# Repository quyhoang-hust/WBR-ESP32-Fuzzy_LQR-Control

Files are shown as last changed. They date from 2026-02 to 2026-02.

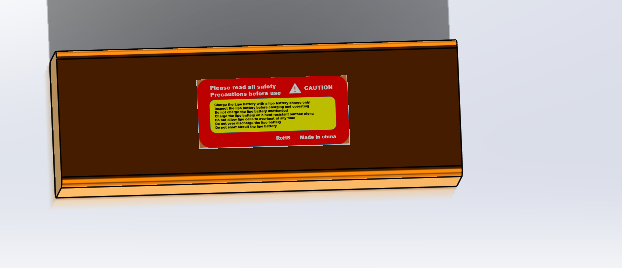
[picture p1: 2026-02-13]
Hardware/lipo-battery-12v-1.snapshot.17/2.PNG

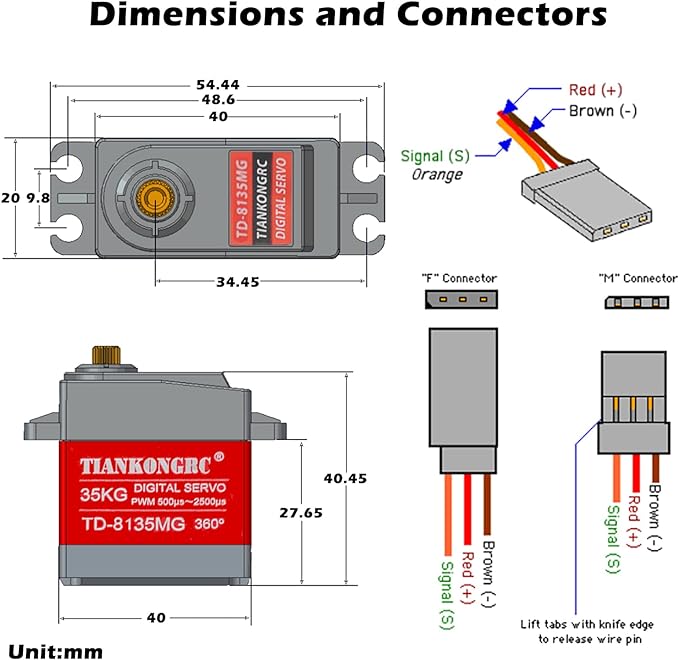
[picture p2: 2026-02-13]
Hardware/servo/TD-8135MG.jpg

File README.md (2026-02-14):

# 🤖 WBR with Fuzzy-LQR Controller
### Wheeled-Bipedal Technology | Advanced Control Systems

Dự án nghiên cứu và triển khai hệ thống điều khiển phản hồi trạng thái (LQR) kết hợp logic mờ (Fuzzy) cho robot lưỡng thăng có bánh (WBR) trên nền tảng ESP32.

## 🧠 Kiến trúc điều khiển (Control Architecture)
Dự án thực hiện bài toán cân bằng động cho robot bằng cách kết hợp giữa lý thuyết điều khiển hiện đại và logic mờ:

* **LQR (Linear Quadratic Regulator):** Sử dụng bộ điều khiển phản hồi trạng thái $u = -Kx$ để giữ thăng bằng. Hệ thống dựa trên vector trạng thái bao gồm: $[ \theta, \dot{\theta}, x, \dot{x} ]^T$.
* **Fuzzy Logic (Gain Scheduling):** Đóng vai trò là bộ điều chỉnh thông số thông minh. Dựa vào góc khớp chân thực tế (`servoAngle`), hệ thống thực hiện nội suy các thông số $K$ và $Target Angle$ phù hợp thông qua hàm membership tam giác (Low, Mid, High).
* **Complementary Filter (Bộ lọc bù):** Xử lý tín hiệu từ MPU6050 với hệ số $\alpha = 0.98$ để triệt tiêu nhiễu của gia tốc kế và hiện tượng trôi (drift) của con quay hồi chuyển, đảm bảo dữ liệu góc nghiêng $\theta$ luôn ổn định.

## 🏗 Kiến trúc phần mềm (Software Architecture)
Mã nguồn được thiết kế theo hướng **Modular Programming**, tận dụng tối đa khả năng xử lý song song trên **Dual-core** của ESP32 thông qua **FreeRTOS**:

### **Core 1: High Priority (Nhiệm vụ điều khiển)**
* **TaskSensor (100Hz):** Đọc cảm biến I2C, tính toán bộ lọc bù và giải mã Encoder.
* **TaskController (100Hz):** Thực thi thuật toán Fuzzy + LQR. Tính toán tín hiệu điện áp $u$ và đẩy vào hàng đợi (`Queue`).
* **TaskMotor:** Chấp hành tín hiệu PWM điều khiển driver BTS7960 với tần số 5kHz.

### **Core 0: Low Priority (Nhiệm vụ phụ trợ)**
* **TaskPosture (20Hz):** Quản lý khớp chân qua RC Servos với tính năng **Smooth Transition** (thay đổi 1° mỗi chu kỳ) để bảo vệ cơ cấu cơ khí.
* **TaskDebug:** Giao tiếp Serial, nhận lệnh thay đổi chiều cao thời gian thực và xuất dữ liệu ra Serial Plotter.

## 📺 Video vận hành thực tế
<div align="center">
  <a href="https://www.youtube.com/watch?v=h3YY7-l_Uk0">
    WBR Robot Balancing
  </a>
  <br>
  <b>Nhấn vào hình ảnh trên để xem video demo trên YouTube</b>
</div>

## 📂 Tổ chức mã nguồn
* `Firmware/`: Chứa mã nguồn chính chia theo các khối chức năng (`SensorBlock`, `ControlBlock`, `MotorBlock`,...).
* `Hardware/`: Thiết kế cơ khí, Mô hình 3D.
* `Documentation/`: Sơ đồ nguyên lý, Sơ đồ đi dây, Hình ảnh robot vận hành và kết quả mô phỏng/debug.

## 🚀 Hướng dẫn vận hành
1. Nạp code vào ESP32 thông qua Arduino IDE hoặc PlatformIO.
2. Mở **Serial Monitor/Plotter** ở baudrate `115200`.
3. Để thay đổi độ cao robot: Nhập giá trị góc từ `115` đến `155` vào Serial. Hệ thống Fuzzy sẽ tự động điều chỉnh bộ tham số $K$ tương ứng.

---
**Author:** Hoang Xuan Quy
**Project Status:** Đã cập nhật đầy đủ chức năng Fuzzy + LQR và RTOS.

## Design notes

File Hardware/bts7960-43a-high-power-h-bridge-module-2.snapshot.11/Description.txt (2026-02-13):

BTS7960 43A High Power H Bridge Module

https://grabcad.com/library/bts7960-43a-high-power-h-bridge-module-1

Buy Link:
https://www.aliexpress.us/item/3256805818916954.html

#CAD #SolidWorks #3dmodel #BTS7960 #43A #HBridge #DCMotors

The nice thing I like about this driver is I am able to control motor direction with 4 pins on the Arduino:
L_EN, R_EN, LPWM, RPWM

BTS7960B H-bridge 43A high-power motor driver Module Overview:

This driver uses Infineon chips BTS7960 composed of high-power drive full H-bridge driver module with thermal over-current protection.

Double BTS7960 H-bridge driver circuit, with a strong drive and braking, effectively isolating the microcontroller and motor driver!

Features:

Double BTS7960 large current (43 A) H bridge driver;

5V isolate with MCU, and effectively protects MCU;

5V power indicator on board;

Voltage indication of motor driver output end;

Can solder heat sink;

Just need four lines from MCU to driver module
(GND. 5V. PWM1. PWM2);

Isolation chip 5 V power supply
(can share with MCU 5 V);

SIZE: 4 * 5 * 1.2 cm;

Two PWM input frequency up to 25kHZ;

Supply voltage 5.5V to 27V;

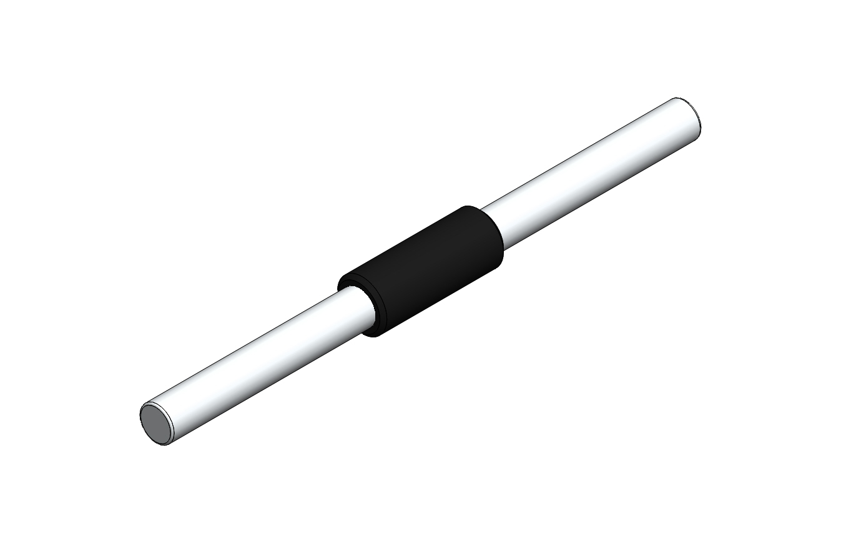
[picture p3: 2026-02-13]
Hardware/mpu-6050-sensor-1.snapshot.1/Gyroscopic sensor/Gyroscope sensor straight lead.JPG

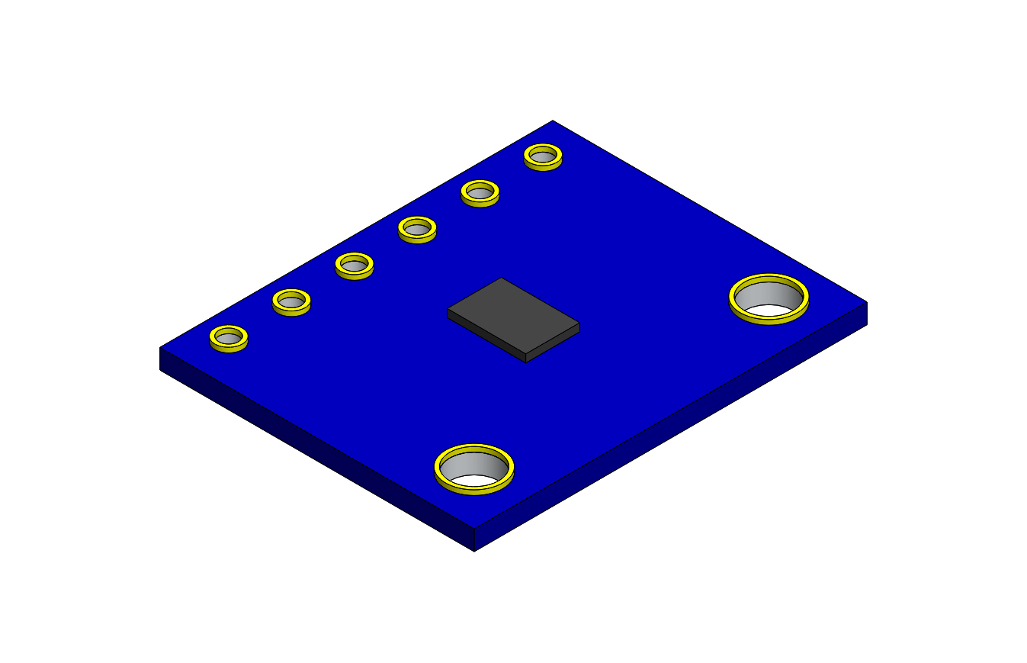
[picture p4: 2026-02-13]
Hardware/mpu-6050-sensor-1.snapshot.1/Gyroscopic sensor/Gyroscope sensor.JPG

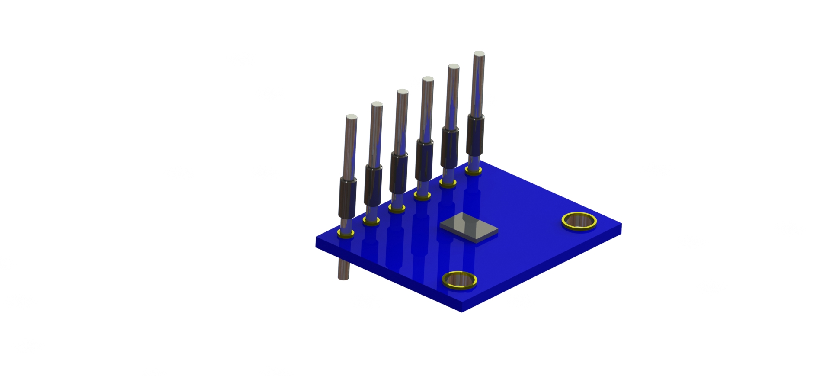
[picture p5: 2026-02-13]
Hardware/mpu-6050-sensor-1.snapshot.1/Gyroscopic sensor/MPU 6050 RENDER.JPG

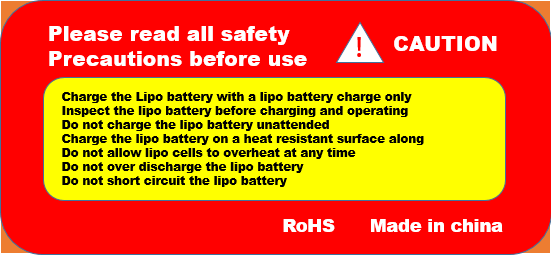
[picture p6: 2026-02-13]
Hardware/lipo-battery-12v-1.snapshot.17/pin2.PNG

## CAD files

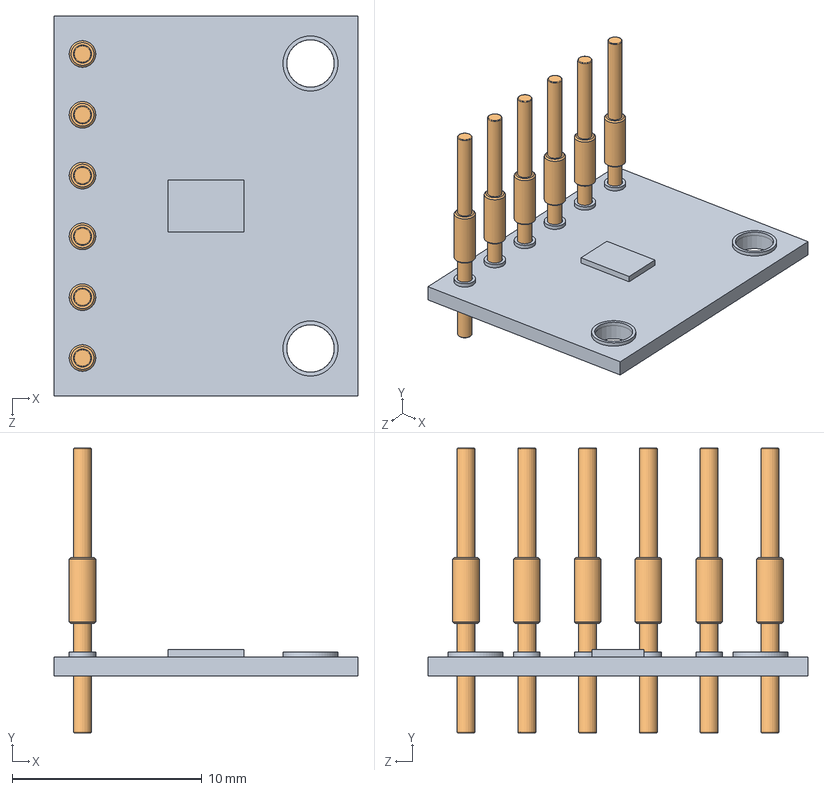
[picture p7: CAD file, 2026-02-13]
Hardware/mpu-6050-sensor-1.snapshot.1/Gyroscopic sensor/Gyrosensor.SLDASM
16.0 x 15.0 x 20.0 mm
Gyroscope sensor
Gyroscope sensor straight lead x 6

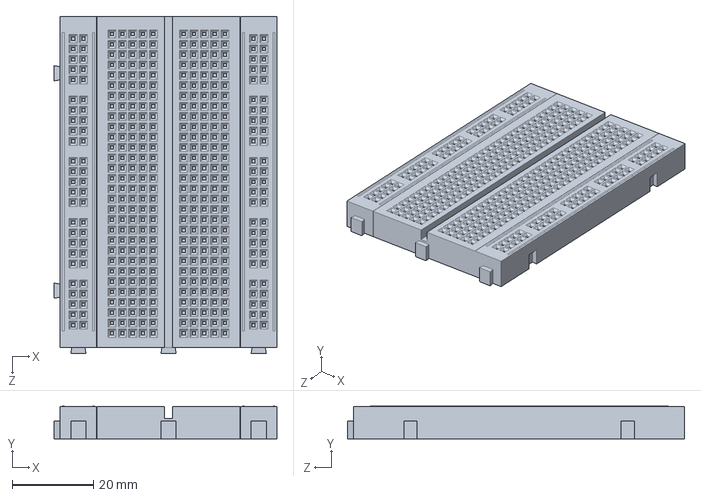
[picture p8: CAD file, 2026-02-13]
Hardware/breadboard-13.snapshot.4/Breadboard_400pin.SLDPRT
54.9 x 8.01 x 83.0 mm

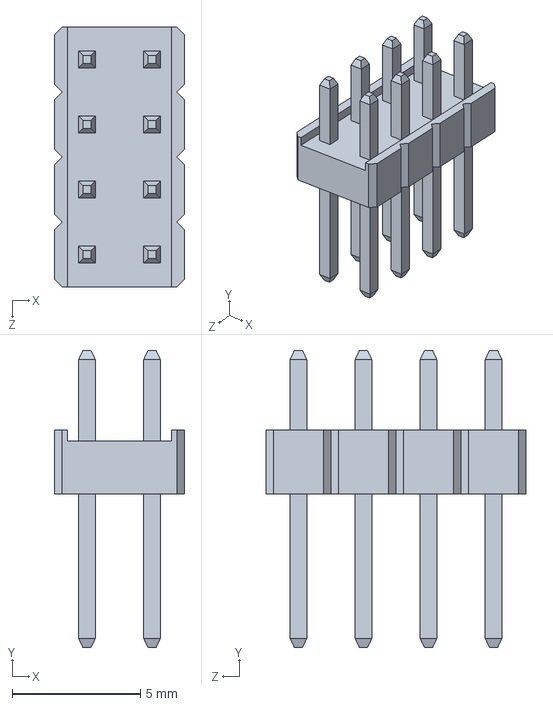
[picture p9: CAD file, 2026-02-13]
Hardware/bts7960-43a-high-power-h-bridge-module-2.snapshot.11/8 PIN HEADER, IC, BTS7960 43A HIGH POWER H BRIDGE MODULE.SLDPRT
5.08 x 11.6 x 10.2 mm

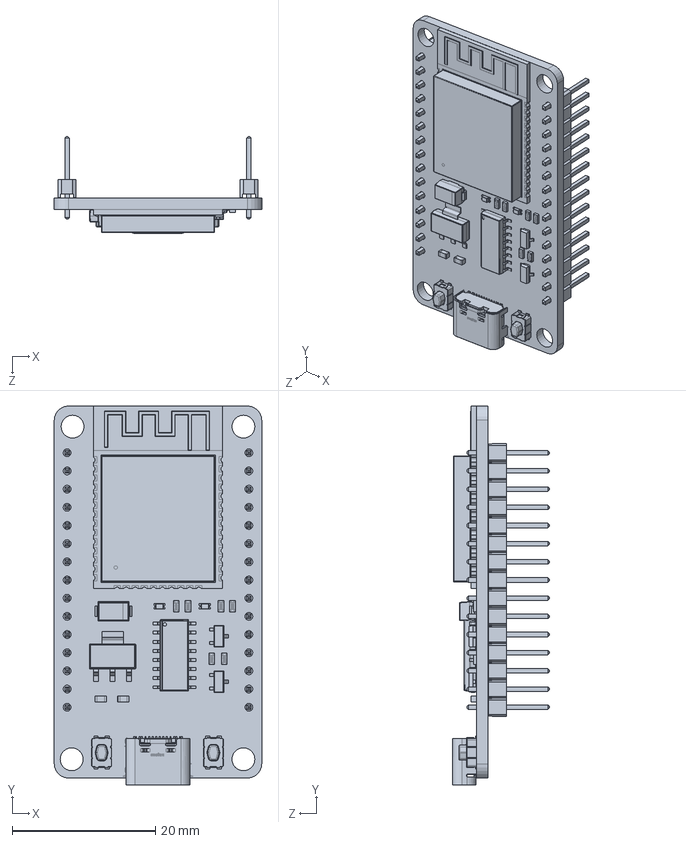
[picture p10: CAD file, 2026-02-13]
Hardware/development-board-esp32-ch340-1.snapshot.2/esp32_30pin_CH340.SLDPRT
29.0 x 53.0 x 13.5 mm

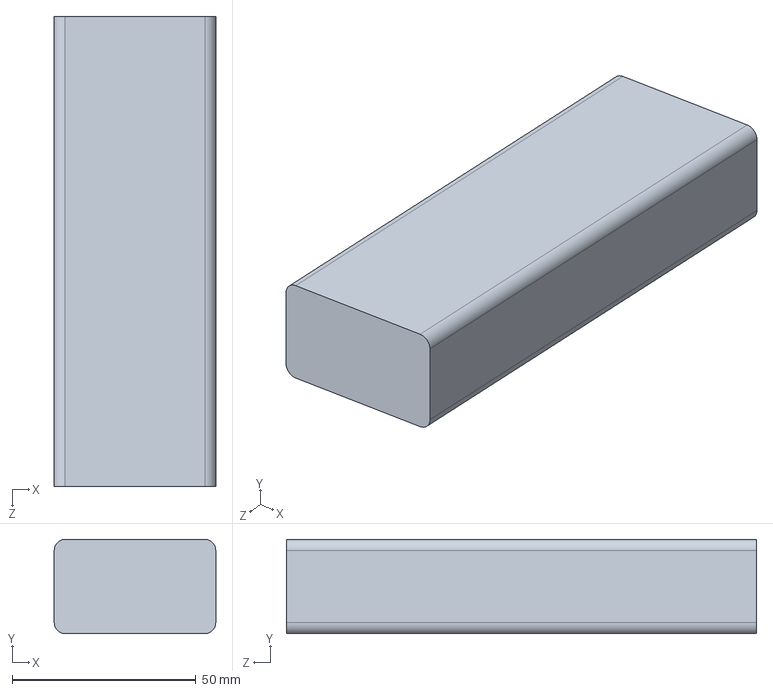
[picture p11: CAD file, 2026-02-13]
Hardware/lipo-battery-12v-1.snapshot.17/Lipo_Battery_12v_step.STEP
44.0 x 25.7 x 128.0 mm

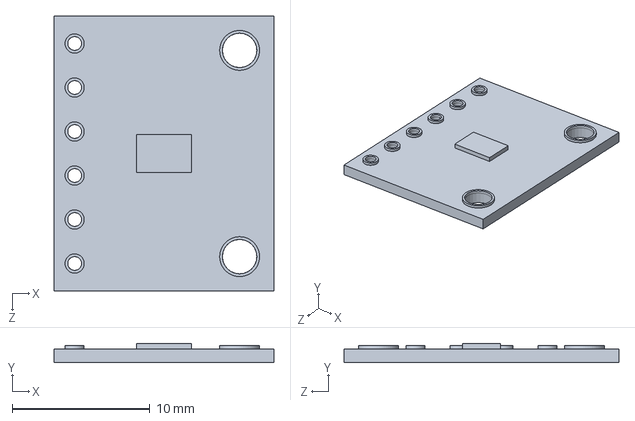
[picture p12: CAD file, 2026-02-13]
Hardware/mpu-6050-sensor-1.snapshot.1/Gyroscopic sensor/Gyroscope sensor.SLDPRT
16.0 x 1.40 x 20.0 mm

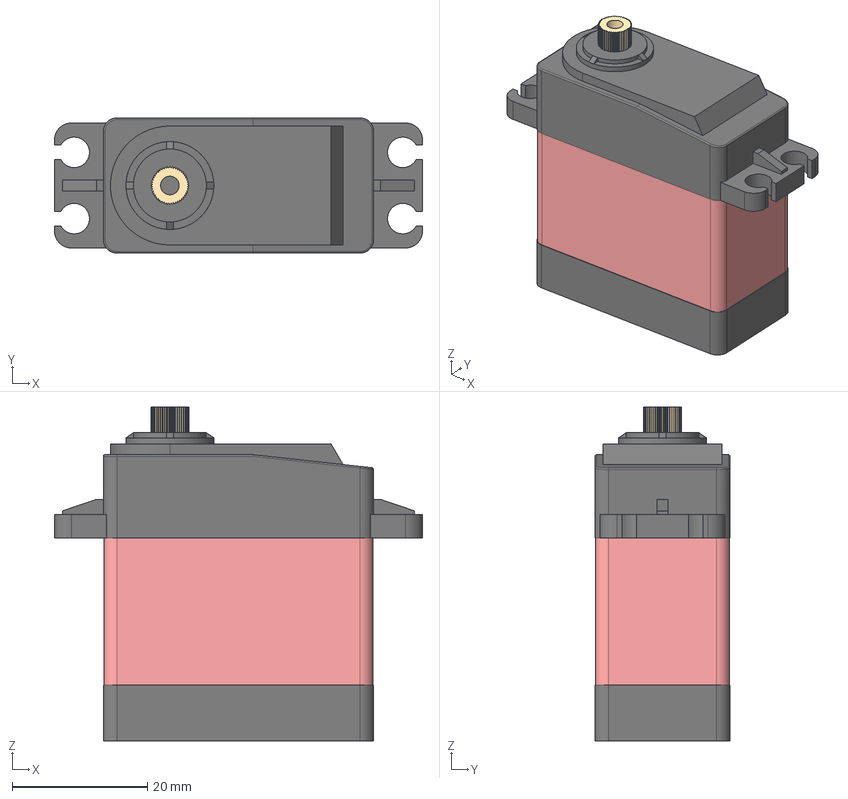
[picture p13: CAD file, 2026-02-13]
Hardware/servo/TD-8135MG Servo v5.step
54.4 x 20.0 x 49.4 mm

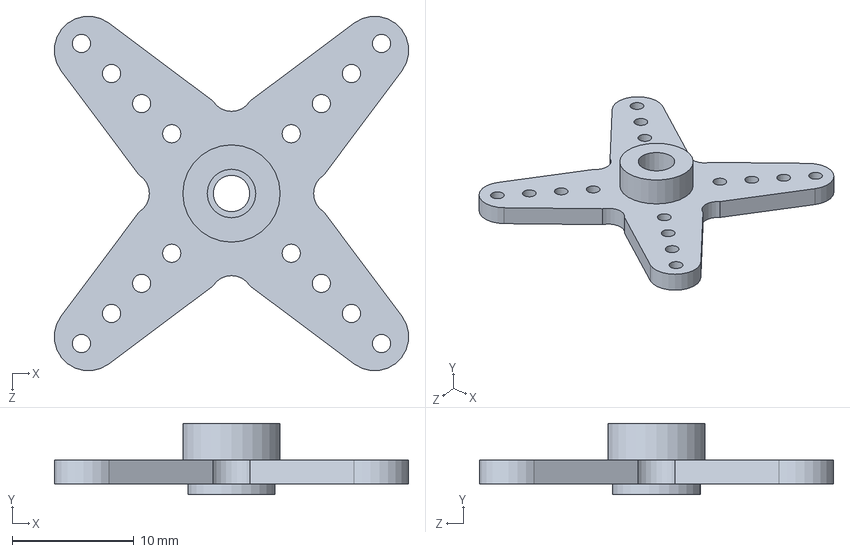
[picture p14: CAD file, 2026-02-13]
Hardware/servo_horn/futaba_horn_type_A.SLDPRT
29.1 x 5.85 x 29.1 mm

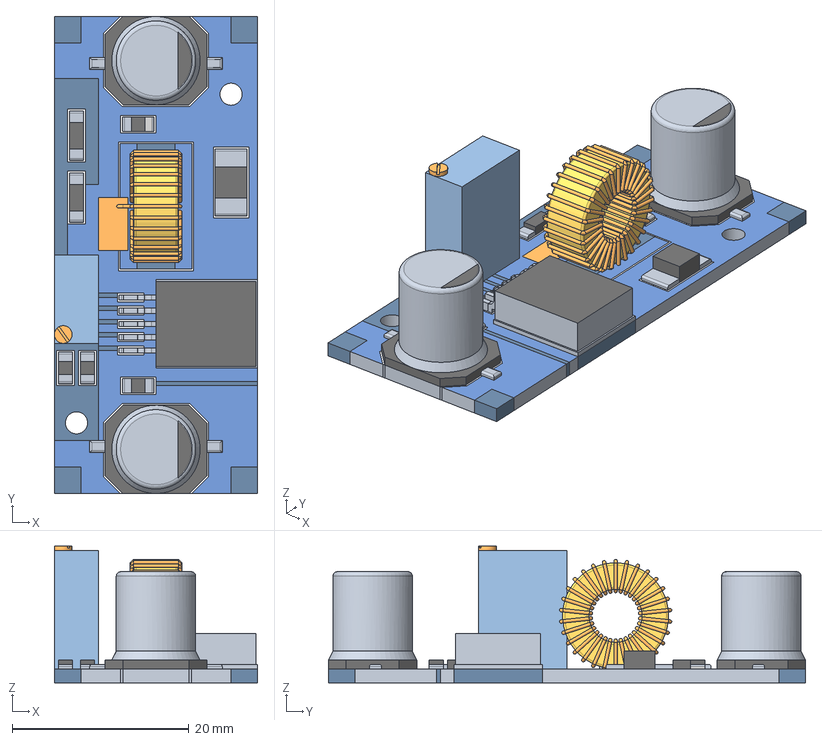
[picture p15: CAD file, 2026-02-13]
Hardware/step-down-xl4015-1.snapshot.2/Step Down XL4015.step
23.0 x 54.0 x 15.5 mm

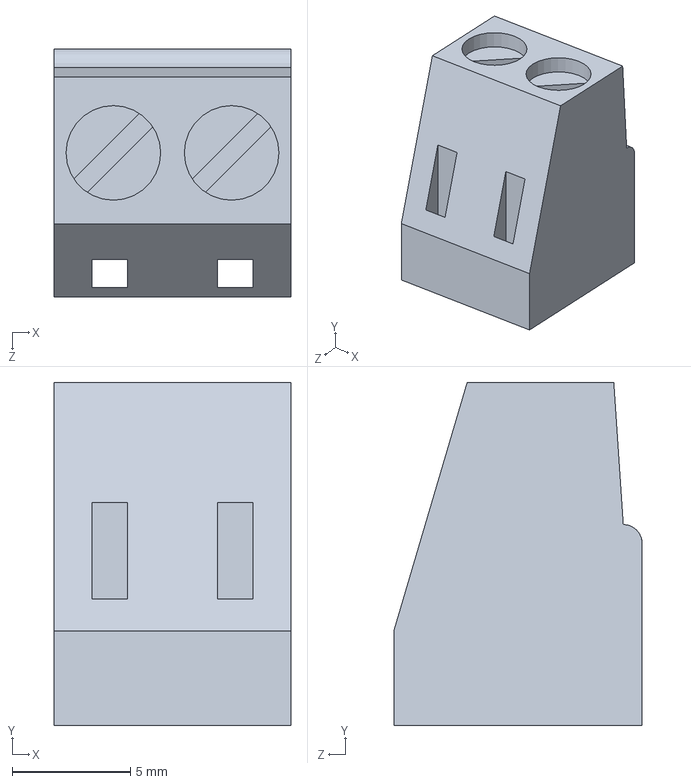
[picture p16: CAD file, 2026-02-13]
Hardware/bts7960-43a-high-power-h-bridge-module-2.snapshot.11/EUROSTYLE TERMINAL BLOCK 2 POS 5.0 MM RA PLUG, BTS7960 43A HIGH POWER H BRIDGE MODULE.SLDPRT
10.0 x 14.5 x 10.5 mm

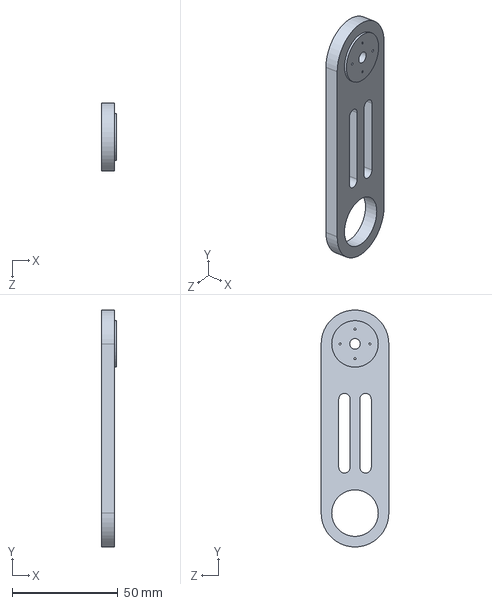
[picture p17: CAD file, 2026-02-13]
Hardware/Leg_Up_Front.SLDPRT
7.00 x 112.0 x 32.0 mm

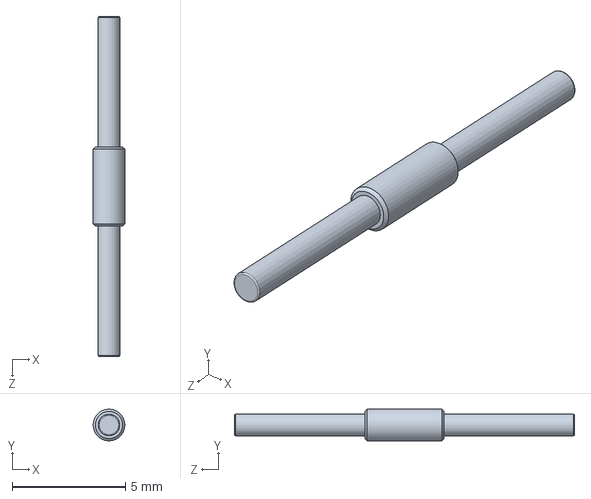
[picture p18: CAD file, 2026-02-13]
Hardware/mpu-6050-sensor-1.snapshot.1/Gyroscopic sensor/Gyroscope sensor straight lead.SLDPRT
1.40 x 1.40 x 15.0 mm

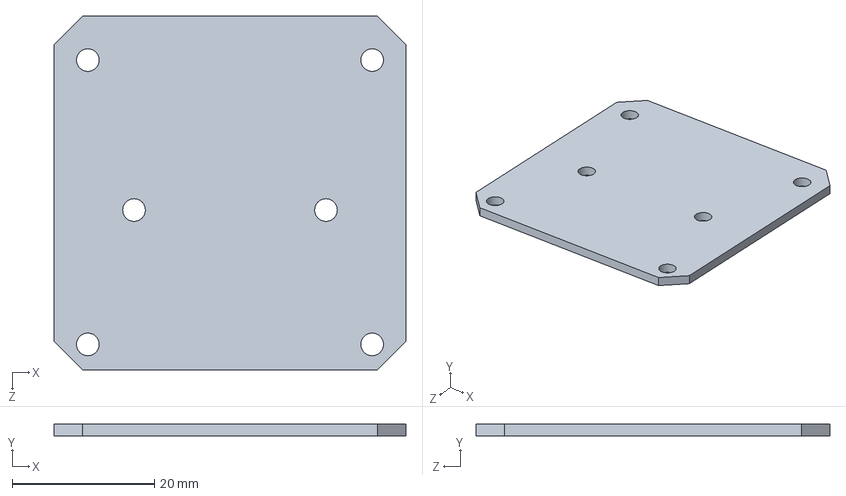
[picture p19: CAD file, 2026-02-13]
Hardware/bts7960-43a-high-power-h-bridge-module-2.snapshot.11/PCB, BTS7960 43A HIGH POWER H BRIDGE MODULE.SLDPRT
49.5 x 1.70 x 49.8 mm

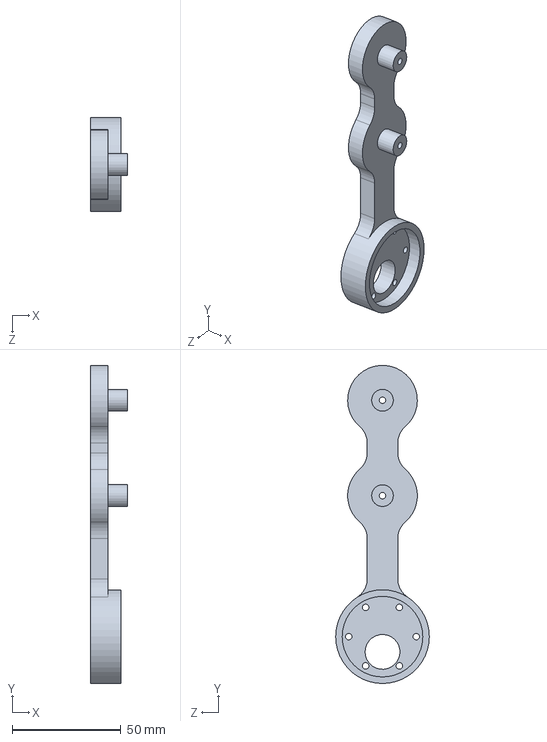
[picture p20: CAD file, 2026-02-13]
Hardware/Leg_Down.SLDPRT
17.0 x 145.9 x 43.0 mm

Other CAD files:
Hardware/lipo-battery-12v-1.snapshot.17/Lipo_Battery_12v.SLDPRT
Hardware/servo/TD-8135MG Servo.SLDPRT
Hardware/lipo-battery-12v-1.snapshot.17/Lipo_Battery_12v_IGES.IGS
Hardware/bts7960-43a-high-power-h-bridge-module-2.snapshot.11/HEATSINK, BTS7960 43A HIGH POWER H BRIDGE MODULE.SLDPRT
Hardware/Leg_Down - Copy.SLDPRT
Hardware/Leg_Up_Back.SLDPRT
Hardware/bts7960-43a-high-power-h-bridge-module-2.snapshot.11/ALUMINUM ELECTROLYTIC CAPACITOR, 330 uF, BTS7960 43A HIGH POWER H BRIDGE MODULE.SLDPRT
Hardware/bts7960-43a-high-power-h-bridge-module-2.snapshot.11/BTN7960 IC, BTS7960 43A HIGH POWER H BRIDGE MODULE.SLDPRT
Hardware/bts7960-43a-high-power-h-bridge-module-2.snapshot.11/BTS7960 43A HIGH POWER H BRIDGE MODULE.SLDASM
Hardware/bts7960-43a-high-power-h-bridge-module-2.snapshot.11/BTS7960 43A HIGH POWER H BRIDGE MODULE.STEP
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

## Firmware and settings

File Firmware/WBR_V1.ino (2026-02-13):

#include <Arduino.h>
#include <freertos/FreeRTOS.h>

#include "SensorBlock.h"
#include "PostureBlock.h"
#include "ControlBlock.h"
#include "MotorBlock.h"
#include "DebugBlock.h"

// --- KHAI BÁO BIẾN TOÀN CỤC ---
SemaphoreHandle_t xStateMutex; 
QueueHandle_t queueMotor;     
RobotState robotState;        

void setup() {
  Serial.begin(115200);
  Serial.println("--- WRB SYSTEM STARTING ---");

  //Khởi tạo RTOS
  xStateMutex = xSemaphoreCreateMutex();
  queueMotor = xQueueCreate(1, sizeof(MotorCommand));

  setupPosture();

  //Khởi tạo giá trị ban đầu
  robotState.height = 0.16;
  robotState.theta = 0.0;
  robotState.x = 0.0;
  robotState.theta_dot = 0.0;
  robotState.x_dot = 0.0;

  //TẠO TASK (ĐÃ BẬT TẤT CẢ)
  
  // Core 1
  xTaskCreatePinnedToCore(TaskSensor, "Sens", 4096, NULL, 4, NULL, 1);
  xTaskCreatePinnedToCore(TaskController, "Ctrl", 4096, NULL, 3, NULL, 1);
  xTaskCreatePinnedToCore(TaskMotor, "Mot", 2048, NULL, 2, NULL, 1);

  // Core 0
  xTaskCreatePinnedToCore(TaskDebug, "Dbg", 2048, NULL, 1, NULL, 0);
  xTaskCreatePinnedToCore(TaskPosture, "Post", 2048, NULL, 1, NULL, 0);
}

void loop() {
  vTaskDelete(NULL);
}

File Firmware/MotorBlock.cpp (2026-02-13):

#include "MotorBlock.h"

#define MAX_VOLTAGE 12.0
#define DEADZONE    20
#define PWM_FREQ    5000
#define PWM_RES     8

void setMot(int pin_rpwm, int pin_lpwm, float v) {
  if (v > MAX_VOLTAGE) v = MAX_VOLTAGE;
  if (v < -MAX_VOLTAGE) v = -MAX_VOLTAGE;

  int pwm = (int)(abs(v) / MAX_VOLTAGE * 255.0);
  
  if (pwm < DEADZONE) {
    ledcWrite(pin_rpwm, 0); 
    ledcWrite(pin_lpwm, 0); 
    return;
  }
  
  if (v > 0) { 
    ledcWrite(pin_rpwm, pwm); 
    ledcWrite(pin_lpwm, 0); 
  }
  else { 
    ledcWrite(pin_rpwm, 0); 
    ledcWrite(pin_lpwm, pwm); 
  }
}

void TaskMotor(void *pvParameters) {
  // ESP32 Core v3.0+
  ledcAttach(PIN_RPWM_L, PWM_FREQ, PWM_RES);
  ledcAttach(PIN_LPWM_L, PWM_FREQ, PWM_RES);
  ledcAttach(PIN_RPWM_R, PWM_FREQ, PWM_RES);
  ledcAttach(PIN_LPWM_R, PWM_FREQ, PWM_RES);

  MotorCommand cmd;

  for (;;) {
    if (xQueueReceive(queueMotor, &cmd, portMAX_DELAY)) {
      setMot(PIN_RPWM_L, PIN_LPWM_L, cmd.voltageL);
      setMot(PIN_RPWM_R, PIN_LPWM_R, cmd.voltageR);
    }
  }
}

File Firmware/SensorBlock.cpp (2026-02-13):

#include "SensorBlock.h"
#include <Wire.h>

#define ALPHA 0.98
#define ALPHA_GYRO 0.7 // Low-pass filter cho gyro (0.5-0.8, nhỏ = mượt hơn)
#define DT_MS 10
#define DT_S 0.01

// Thông số cơ khí: R=0.0325m, Encoder 11 xung, Hộp số 30
const float METERS_PER_COUNT = (2 * PI * 0.0325) / (11.0 * 30.0);

volatile long encCountL = 0;
volatile long encCountR = 0;
portMUX_TYPE muxEnc = portMUX_INITIALIZER_UNLOCKED;

void IRAM_ATTR isr_EncL() {
  portENTER_CRITICAL_ISR(&muxEnc);
  if (digitalRead(ENC_L_B))
    encCountL++;
  else
    encCountL--;
  portEXIT_CRITICAL_ISR(&muxEnc);
}

void IRAM_ATTR isr_EncR() {
  portENTER_CRITICAL_ISR(&muxEnc);
  if (digitalRead(ENC_R_B))
    encCountR++;
  else
    encCountR--;
  portEXIT_CRITICAL_ISR(&muxEnc);
}

// Đọc MPU6050 đơn giản, trả về true nếu thành công
bool readMPU(int16_t *accX, int16_t *accZ, int16_t *gyrY) {
  Wire.beginTransmission(MPU_ADDR);
  Wire.write(0x3B);
  if (Wire.endTransmission(false) != 0) {
    return false; // I2C lỗi
  }

  uint8_t count =
      Wire.requestFrom((uint8_t)MPU_ADDR, (uint8_t)14, (uint8_t)true);
  if (count != 14) {
    // Clear buffer nếu có
    while (Wire.available())
      Wire.read();
    return false;
  }

  *accX = Wire.read() << 8 | Wire.read();
  Wire.read();
  Wire.read(); // accY - bỏ qua
  *accZ = Wire.read() << 8 | Wire.read();
  Wire.read();
  Wire.read(); // Temp - bỏ qua
  Wire.read();
  Wire.read(); // gyrX - bỏ qua
  *gyrY = Wire.read() << 8 | Wire.read();
  Wire.read();
  Wire.read(); // gyrZ - bỏ qua

  return true;
}

void initMPU6050() {
  Wire.begin(21, 22);    // SDA=21, SCL=22 (mặc định ESP32)
  Wire.setClock(400000); // 400kHz I2C

  // Wake up MPU6050
  Wire.beginTransmission(MPU_ADDR);
  Wire.write(0x6B);
  Wire.write(0x00);
  Wire.endTransmission(true);

  // Gyro config: ±250°/s
  Wire.beginTransmission(MPU_ADDR);
  Wire.write(0x1B);
  Wire.write(0x00);
  Wire.endTransmission(true);

  // Accel config: ±2g
  Wire.beginTransmission(MPU_ADDR);
  Wire.write(0x1C);
  Wire.write(0x00);
  Wire.endTransmission(true);

  Serial.println("[SENSOR] MPU6050 OK");
}

void TaskSensor(void *pvParameters) {
  initMPU6050();

  // Encoder pins - Lưu ý: GPIO 34-39 không có internal pull-up
  pinMode(ENC_L_A, INPUT);
  pinMode(ENC_L_B, INPUT);
  pinMode(ENC_R_A, INPUT);
  pinMode(ENC_R_B, INPUT);

  attachInterrupt(ENC_L_A, isr_EncL, RISING);
  attachInterrupt(ENC_R_A, isr_EncR, RISING);

  float filtered_theta = 0.0;
  long prevPosL = 0, prevPosR = 0;
  int errorCount = 0;

  // Warm-up: Đọc góc ban đầu
  vTaskDelay(pdMS_TO_TICKS(200));
  int16_t ax, az, gy;
  if (readMPU(&ax, &az, &gy)) {
    filtered_theta = -atan2((float)ax, (float)az);
    Serial.printf("[SENSOR] Init: %.1f deg\n", filtered_theta * 180.0 / PI);
  } else {
    Serial.println("[SENSOR] MPU read FAILED!");
  }

  TickType_t xLastWakeTime = xTaskGetTickCount();

  for (;;) {
    vTaskDelayUntil(&xLastWakeTime, pdMS_TO_TICKS(DT_MS));

    int16_t accX, accZ, gyrY;

    if (readMPU(&accX, &accZ, &gyrY)) {
      errorCount = 0;

      float thetaAcc = -atan2((float)accX, (float)accZ);
      float thetaDot = (gyrY / 131.0f) * (PI / 180.0f); // Đã sửa dấu

      // Complementary filter
      filtered_theta = ALPHA * (filtered_theta + thetaDot * DT_S) +
                       (1.0f - ALPHA) * thetaAcc;

      // Đọc encoder
      portENTER_CRITICAL(&muxEnc);
      long currL = encCountL;
      long currR = encCountR;
      portEXIT_CRITICAL(&muxEnc);

      float x_meters = ((currL + currR) / 2.0f) * METERS_PER_COUNT;
      float x_dot = (((currL - prevPosL) + (currR - prevPosR)) / 2.0f *
                     METERS_PER_COUNT) /
                    DT_S;

      prevPosL = currL;
      prevPosR = currR;

      // Cập nhật state
      if (xSemaphoreTake(xStateMutex, pdMS_TO_TICKS(2))) {
        robotState.theta = filtered_theta;
        robotState.theta_dot = thetaDot;
        robotState.x = x_meters;
        robotState.x_dot = x_dot;
        xSemaphoreGive(xStateMutex);
      }
    } else {
      // Lỗi I2C - chỉ log, không reset (để tránh treo)
      errorCount++;
      if (errorCount % 100 == 0) {
        Serial.printf("[SENSOR] I2C err x%d\n", errorCount);
      }
    }
  }
}
